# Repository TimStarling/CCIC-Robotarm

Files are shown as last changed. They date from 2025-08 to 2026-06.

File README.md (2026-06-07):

<div align="right">

[中文](README.md) | [English](README_EN.md)

</div>

# CCIC-Robotarm
基于海云捷讯的机械臂控制系统-2025年集成电路创新大赛（集创赛）FPGA应用赛道作品（机械臂控制部分）
本项目分为两个工程，视觉识别部分参见另一个仓库（视觉识别部分）
注意：ip核的版本可能和你的quartus不一致，将.qip文件中的版本号改成和你的quartus版本一致即可

基于 FPGA 的机械臂控制工程（2025 集成电路创新大赛 FPGA 应用赛道参赛项目，机械臂控制部分）。本仓库聚焦 **“坐标/仓库信息输入 → 逆解与动作编排 → 串口下发舵机/气泵指令”** 的完整链路。视觉识别侧在另一个仓库中维护。

---

## 1. 项目概述

本设计运行在 Intel Cyclone IV E（EP4CE6F17C8）平台，使用 Quartus Prime Lite 23.1 工程。顶层模块会在触发后完成一次自动搬运流程：

1. 根据目标点 `(x, y)` 计算机械臂姿态（高位/低位）。
2. 串口下发 5 路舵机位姿。
3. 控制气泵吸取/释放物块。
4. 根据仓库编号查询目标仓位坐标与方向。
5. 将物块放置到仓位后回到初始位。

顶层状态机实现了完整时序（等待、抬升、下降、吸放、回零）。

---

## 2. 代码与工程结构

```text
.
├── rtl/                    # Verilog RTL 源码
│   ├── data_send_top.v     # 顶层：流程控制状态机 + 各子模块联动
│   ├── xyz_calculate.v     # 坐标到舵机 PWM 的逆解计算
│   ├── all_instruction.v   # 5 路舵机角度顺序发送调度
│   ├── single_instruction.v# 单条舵机协议发送
│   ├── uart_Robot_tx.v     # 机械臂串口发送
│   ├── uart_tx_pump.v      # 气泵串口发送
│   ├── warehouse.v         # 仓库坐标/方向获取
│   ├── key_detect.v        # 按键消抖与沿检测
│   └── ...
├── quartus_prj/            # Quartus 工程（qpf/qsf/ip/output_files 等）
├── 技术文档.pdf             # 设计说明文档（中文）
└── 参数.txt                # 机械臂参数/调试记录
```

---

## 3. 顶层接口说明（`data_send_top`）

### 输入

- `sys_clk`：系统时钟（工程管脚绑定到 `PIN_E1`）。
- `sys_rst_n`：低有效复位（`PIN_E15`）。
- `key1`：启动按键输入（代码中取反后做按下检测）。
- `uart_rx`：仓库信息串口输入（`PIN_N14`）。
- `rx_camera`：视觉串口输入（`PIN_L13`，当前逻辑中仅透传到测试口）。

### 输出

- `tx_armcontrol`：机械臂舵机串口输出（`PIN_E7`）。
- `tx_pump`：气泵串口输出。
- `tx_done`：一次多舵机串口批量发送完成标志。
- `tx_test`：测试口（当前接 `rx_camera` 透传，`PIN_G1`）。
- `control_finish`：整套抓取放置流程完成标志。

---

## 4. 核心流程（状态机）

顶层 `state` 从 `d0` 到 `d24` 组织整个流程，关键阶段如下：

- **启动与参数锁存**：检测按键触发，锁存当前目标和偏移量。
- **物料区高位 → 低位**：先到高处，再下降抓取。
- **气泵吸取**：下发吸气指令并延时等待稳定。
- **查询仓位**：通过 `warehouse` 模块获取目标仓位坐标与方向。
- **仓位高位/低位放置**：到仓库高位、下降、放置、再抬升。
- **回初始位并结束**：回到默认姿态，置 `control_finish=1`。

> 说明：当前版本里视觉输入模块 `uart_camera` 实例被注释，`x_input/y_input` 在上电后有默认值（`132/80`），适合联调与离线动作验证。

---

## 5. 开发环境与构建

- Quartus Prime Lite: **23.1std.0**（工程创建版本）
- Device: **EP4CE6F17C8**
- Top-level entity: **`data_send_top`**

### 编译步骤

1. 打开 `quartus_prj/Robot_arm.qpf`。
2. 检查 IP 是否可用；若版本不一致，按本机 Quartus 版本重新生成或调整 `.qip` 关联。
3. 运行 `Analysis & Synthesis`、`Fitter`、`Assembler`。
4. 在 `quartus_prj/output_files/` 获取 `Robot_arm.sof` 并下载到 FPGA。

---

## 6. 串口与联调建议

- 机械臂舵机与气泵各自独立串口发送，请确认外设波特率与协议匹配。
- `all_instruction` 采用“单舵机逐条发送 + 延时”策略，便于避免总线拥塞。
- 若接入视觉仓库联动，建议先单独验证：
  1. `xyz_calculate` 输出范围；
  2. `warehouse` 返回坐标/方向的时序；
  3. 气泵指令在各状态的触发时机。

---

## 7. 已知注意事项

1. **IP 版本兼容性**：跨 Quartus 版本时，`.qip` / IP 可能需重新生成。
2. **工程输出目录较大**：`quartus_prj/db`、`output_files` 为编译产物。
3. **视觉模块默认未使能**：如需在线视觉坐标，请恢复 `uart_camera` 实例并检查协议。

---

## 8. 后续可优化方向

- 恢复并标准化视觉输入协议，形成完整闭环自动分拣。
- 将状态机中的固定延时改为可配置参数（或依据反馈闭环结束）。
- 增加仿真 testbench（坐标、仓位、串口返回场景）。
- 增加异常处理：串口超时、仓位无效、吸取失败重试。

---

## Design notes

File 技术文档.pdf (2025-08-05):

1

# 第九届

# 全国大学生集成电路创新创业大赛

报告类型： | 技术报告
参赛杯赛： | 海云捷讯杯

## 作品名称：基于海云捷讯 FPGA 的机械臂精确控制系统设计

队伍编号： | CICC0902660
团队名称： | I'm milk dragon

2

## 基于海云捷讯 FPGA 的机械臂精确控制系统设计 —

## — 快速预览简介

一、核心系统架构
本作品以海云捷讯 AWC_C4 DVK 开发板的 Cyclone IV 系列 FPGA （EP4CE6F17C8N）为核心，构建了集图像采集、处理、机械臂控制于一体的精 确控制系统。系统外接 OV5640 摄像头（720P 分辨率，RGB565 格式）实时采 集图像，经 FPGA 处理后通过 VGA 接口显示；SDRAM 模块（HY57V2562GTR， 256Mbit）用于图像缓存，采用乒乓操作实现跨时钟域（84MHz 摄像头输入 / 75MHz VGA 输出）数据同步；通过串口与 6 自由度飞特总线舵机通信，完成物 块抓取与放置。
二、关键技术亮点
1. 视觉处理优化方案
色块识别：采用 RGB 转 YCbCr 颜色空间转换（公式： Y=0.299R+0.587G+0.114B，Cb、Cr 同理），相比 HSV 减少 FPGA 逻辑资源 占用，实现 95%-100% 的颜色识别正确率（红色、蓝色 100%，黄色 98%， 黑色 95%）。
边缘检测：基于 Sobel 算子的 4 级流水处理，通过缓存 3 列像素计算水 平 / 垂直梯度，快速提取物块边框，为形状识别奠定基础。 角度计算：结合颜色角点（Z 字型扫描逐次逼近获取）与边缘角点（边框范 围内检测），利用 CORDIC 算法实现反正切计算，正方形、三角形角度误差 ±2°-6°，圆形、六边形通过对称性修正后精度提升。
2. 机械臂控制高效实现
逆运动学解算：采用基于余弦定理的方案，通过 Matlab 预计算所有可能坐 标对应的关节角度及 PWM 值，生成 ROM 表（如以 X、Y 为地址存储 PWM0 和 R 值），FPGA 查表调用，减少 90% 以上实时计算资源占用，角度误差 ±0.1°，末端定位误差 < 1mm。
PWM 控制：12 位精度（4096 级），舵机角度误差 ±1 步进，配合状态机 实现抓取 - 放置全流程自动化，单目标处理链路延迟 < 20ms。 三、核心性能指标
识别精度：颜色识别综合正确率 98%，形状识别中正方形 98%、三角形 93%、圆形 90%、六边形 89%；角度计算误差最大 6°（正方形 135° 时）。

3

控制精度：机械臂抓取成功率 86%-96%（中心区域最高 96%），逆运动学解 算末端误差 < 1mm，PWM 输出精度满足舵机 0.09°/step 控制需求。 实时性：图像处理支持 30fps 视频流，单帧处理时间 < 33ms；控制闭环 （图像采集到指令输出）延迟 < 20ms。
资源占用：采用 ROM 查表方案后，FPGA 逻辑资源占用 84%，记忆资源占用 75%。
系统已满足赛题难度 1、2 要求，当前物块放置精度 90%。

4

目录

5

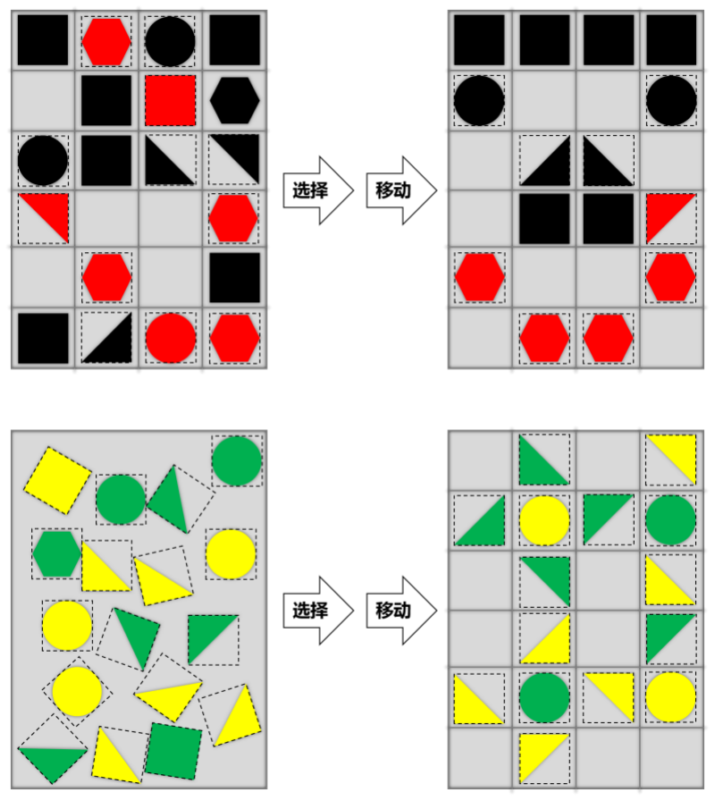
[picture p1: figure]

6

## 1 系统架构分析

1.1 赛题介绍

本赛题内容为控制多自由度机械臂完成将一定数量含有不同形状和颜色图 案的正方形物块，按照指定规则进行仓库至目的地的移动、拼接和还原。 示意图如图 1 所示：

图 1.1 设计要求示意图
本赛题要实现的内容：
1、传感器数据处理：FPGA 可以实时处理来自 OV5640 图像传感器的数据， 对图像数据实时进行 RGB 转 YCbCr、图像二值化、生长算法、目标检测、颜色 识别、计算坐标等算法实现。
2、运动控制算法实现：通过 FPGA 实现机械臂的运动控制算法，在 Matlab 中完成逆运动学计算、ROM 设计、轨迹规划控制。将这些算法可以通过硬件描 述语言实现，利用 FPGA 的并行计算能力对算法加速处理。 3、通信接口设计：本设计需要用到 IIC、UART、VGA 等接口，实现摄像头 参数配置、机械臂串口通信、调试串口通信、图像显示等功能。各接口通过 FPGA 并行处理能力实现同步运行，确保摄像头配置、机械臂控制、调试监控及 图像显示功能高效协同。
1.2 系统总体设计

本系统以 FPGA（EP4CE6F17C8）为核心控制器，构建起集图像处理、特征提 取、机械臂控制于一体的高精度运动控制系统，实现对目标物体的精准抓取与

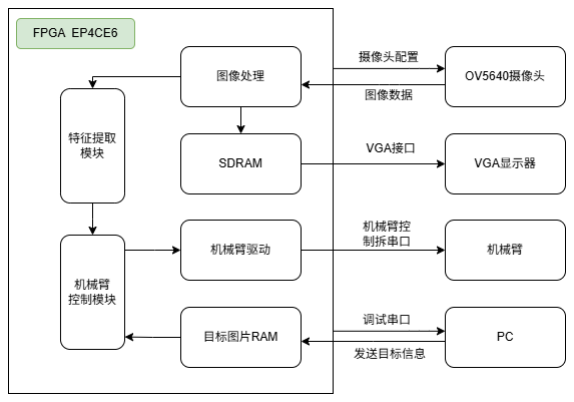
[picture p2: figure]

7

操作。系统外接 OV5640 摄像头实时采集场景图像，经 FPGA 内部图像处理模块 进行 RGB565 转 YCbCr、灰度二值化、腐蚀膨胀算法、目标检测生长算法和颜色 识别等处理，提升图像质量并提取目标特征、坐标等数据，处理后将图像数据 存入 SDRAM 缓存，同时通过 VGA 接口输出至显示器以便实时监控。特征提取模 块对处理后的图像进行分析，计算目标物体的坐标、形状、颜色等关键信息并 传递给机械臂控制模块，该模块结合逆运动学计算、轨迹规划等算法生成机械 臂各关节控制指令，通过机械臂控制串口发送至驱动模块，精准驱动机械臂执 行抓取动作。目标图片 RAM 用于存储目标物体特征信息以便快速调用匹配，PC 通过调试串口与 FPGA 通信，可发送目标信息或接收系统状态数据进行调试监 控。工作时，OV5640 先采集图像，经 FPGA 处理与特征提取识别目标，机械臂 控制模块中有预先在 Matlab 中计算好的逆运动学 ROM，驱动机械臂完成抓取， 同时 VGA 实时显示图像、PC 端辅助调试确保系统稳定。本组利用 FPGA 并行计 算特性实现图像处理与控制算法高效运行，缩短响应时间，提升实时性，模块 化设计增强可维护性与扩展性，各模块协同保障机械臂运动的高精度与稳定 性，通过整合多模块功能实现图像感知与机械臂控制的深度融合，为机械臂精 确控制提供高效可靠的解决方案。整个系统框图如下 图 1.2 所示：

图 1.2 系统总体框图
1.3 硬件设计

AWC_C4 DVK 是 Cyclone IV E 系列 EP4CE6F17C8N 的一款开发板，芯片 采用 28 纳米工艺。它集成了 6272 个逻辑单元、179 个 I/O 接口，封装为 FBGA - 256 形式，工作电压范围 1.15V~1.25V，工作温度范围 0℃~+85℃，总 RAM 位数达 276480bit。该芯片具备高性能，依托先进工艺与充足逻辑单元， 可实现高速运算与存储；支持用户根据需求编程，灵活实现不同场景下的功 能；开发板板载 SDRAM 为 256Mb，用于缓存图像数据、中间计算结果等，

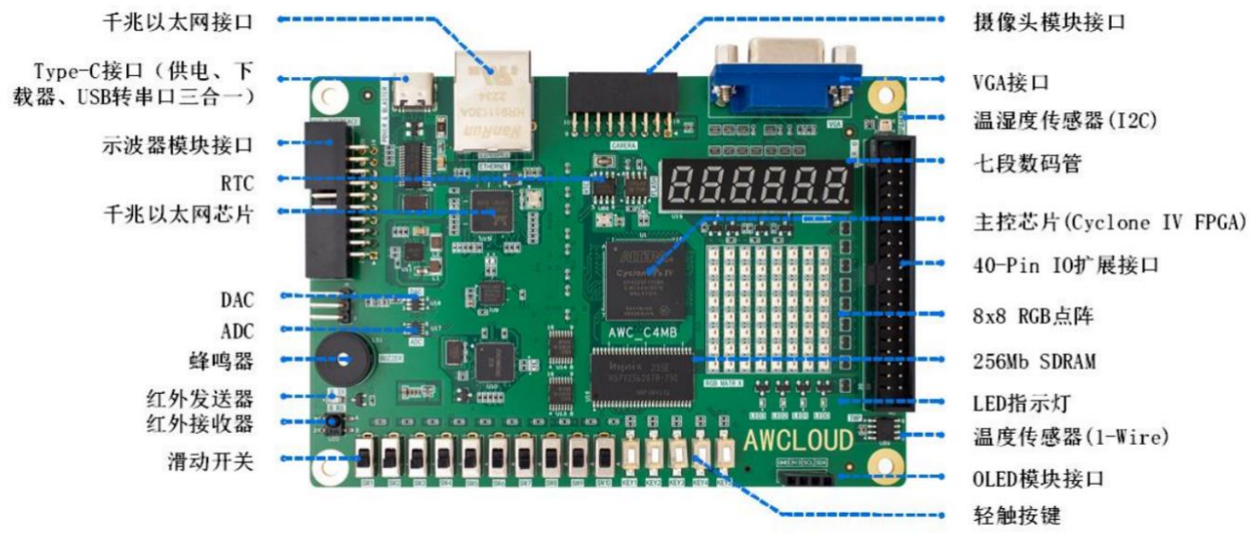
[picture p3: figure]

8

支持 FPGA 高速读写，保障系统数据处理流畅。 VGA 接口 传输模拟信号， 能连接显示器输出处理后的图像，便于调试与显示。 摄像头模块接口可接入摄 像头，为 FPGA 提供图像采集输入，适用于物体识别、图像处理等场景。 按 键为轻触式，用于触发功能或调整参数； 拨码开关则通过滑动设置状态组合， 直观输入配置信息。 拓展口可外接传感器、控制板等设备，灵活扩展系统功 能，增强开发板适用性。其他如电源、指示灯等部分为基础支持，确保各模块 稳定运行。下图为开发板示意图如 1.3 所示：

图 1.3 开发板示意图
1.3.1 SDRAM 模块
AWC_C4 DVK 上设计有 SDRAM 电路，主要用于协助主控芯片内部的命 令发送以及数据传输等。在图像处理系统中，需要对图像视频数据进行缓存， 所以需要大容量存储器。SDRAM 有价格优廉、容量大等优点，常作为 FPGA 的外挂存储器。同步是指其工作需要同步时钟，命令的发送与数据的传输都以 时钟为基准；动态是指存储阵列需要不断的刷新来保证电容存储体中的数据不 丢失；随机是指数据可以自由指定地址进行数据读写。该开发板采用的是 SK Hynix 公司 SDRAM，芯片型号为：HY57V2562GTR，容量为 256Mbit， （4Mx4Bankx16IO）同步动态随机存储器。使用的数据位宽为 16bit，最大工 作频率为 133MHz。
在项目中，OV5640 摄像头负责图像采集，利用 SDRAM 对处理后的图像 数据进行的乒乓操作，和跨时钟域处理。乒乓操作是一种高效的数据缓冲与处 理技术，利用存储模块交替进行数据写入和读出。在第一个缓冲周期，数据写 入模块 1；第二个周期，数据写入模块 2，同时读出模块 1 的数据，循环往 复。通过输入输出数据流选择单元的协同切换，使输入输出数据流连续不断， 可实现数据的无缝缓冲与处理。而跨时钟域操作，因 OV5640 输入的图像时钟 PCLK 为 84Mhz，VGA 的输出时钟为 75Mhz，直接操作易引发数据错误，利用 SDRAM 进行跨时钟域同步，有效解决因时钟域不同导致的数据一致性问题。

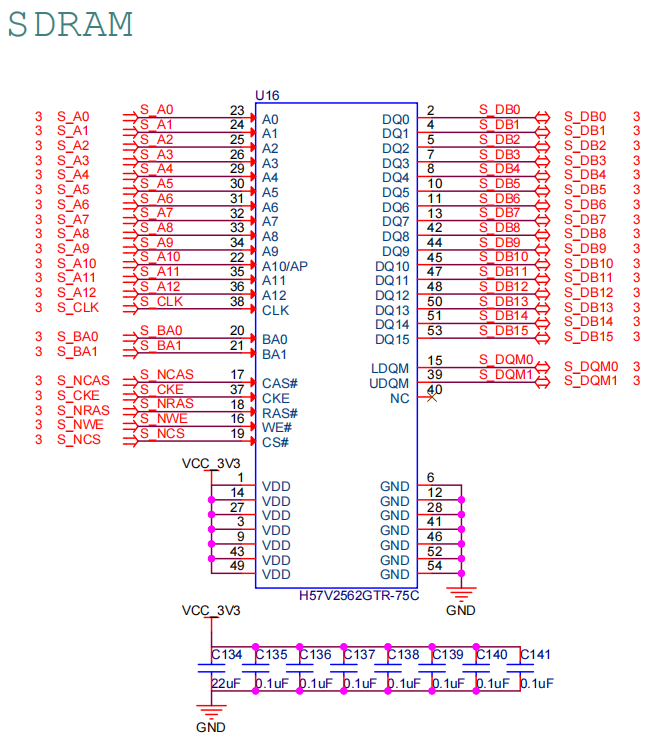
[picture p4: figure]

9

SDRAM 电路图如下图 1.4 所示：

图 1.4 SDRAM 电路图

SDRAM 模块引脚定义如 | 表 1.1 所示：
表 1.1 SDRAM 模块引脚定义表
信号名称 | 端口说明
S_DB0 ~ S_DB15 | SDRAM 数据线 0 ~ 15
S_DQM0 ~ S_DQM1 | SDRAM 数据掩码 0 ~ 1
S_A0 ~ S_A12 | SDRAM 地址线 0 ~ 12
S_BA0 ~ S_BA1 | SDRAM Bank 地址线 0 ~ 1
S_CLK | SDRAM 时钟输入
S_NCAS | SDRAM 列地址选通
S_CKE | SDRAM 时钟使能
S_NRAS | SDRAM 行地址选通
S_NWE | SDRAM 写使能
S_NCS | SDRAM 片选
1.3.2 摄像头模块
该项目用到摄像头模块，型号为 OV5640，实物图如图 1.5 所示：

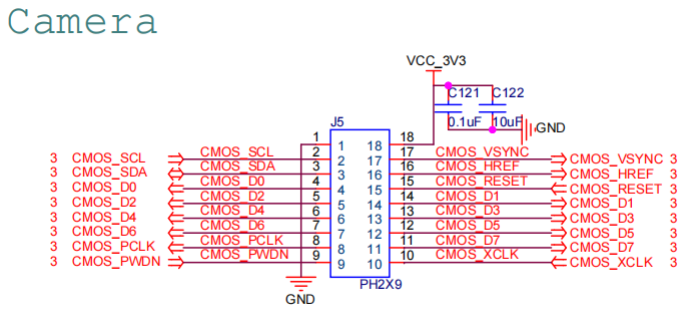
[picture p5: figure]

10

图 1.5 摄像头实物图
OV5640 是一款 CMOS 类型数字图像传感器，该传感器支持输出最大为 500 万像素的图像 (2592x1944 分辨率)，支持使用 VGA 时序输出图像数据， 输出图像的数据格式支持 YUV(422/420)、YCbCr422、RGB565 以及 JPEG 格 式。它还可以对采集得的图像进行补偿，支持伽玛曲线、白平衡、饱和度、色 度等基础处理。根据不同的分辨率配置，传感器输出图像数据的帧率从 15-60 帧可调。其内部有许多寄存器，用来配置摄像头的工作方式、图像格式等等； 在实际应用时需要先使用 SCCB 协议或者是 I2C 协议配置寄存器，使摄像头 按照常见的 VGA 时序输出图像数据。在本次设计中，使用 I2C 协议配置摄 像头，并将 OV5640 分辨率配置为 720P、数据格式为 RGB565 输出。 摄像头接口原理图如下图 1.6 所示：

图 1.6 摄像头接口原理图
摄像头接口模块引脚定义如 | 表 1.2 所示：
表 1.2 摄像头接口引脚定义表
信号名称 | 端口说明
CMOS_D0 ~ CMOS_D7 | 摄像头数据线 D0 ~ D7
CMOS_SCL | 摄像头 I2C 时钟线
CMOS_SDA | 摄像头 I2C 数据线

11

CMOS_PWDN | 摄像头掉电使能
CMOS_HREF | 摄像头行同步信号
CMOS_VSYNC | 摄像头帧同步信号
CMOS_RESET | 摄像头复位
CMOS_XCLK | 摄像头驱动时钟
CMOS_PCLK | 摄像头像素时钟
1.3.3 VGA 显示接口模块
VGA 是视频图像阵列，通常指代 VGA 接口。它是 IBM 在 1987 年推出 的一种视频传输标准，具有分辨率高、显示速率快、颜色丰富等优点，在彩色 显示器领域得到了广泛的应用。它的显示原理是： CRT（阴极射线管）以 “Z”型扫描的方式将阴极射线枪发出的电子束打在涂有荧光粉的荧光屏上， 产生 RGB 三基色合成一个彩色像素，每扫完一行，电子枪都要回到屏幕的下 一行左边的起始位置，并且在换行的过程中，电子枪需要消隐，避免破坏已经 成像的像素。
AWC_C4 DVK 上设计有 1 个 15 针的 D-SUB 接口，主要用于 VGA 输 出。开发板设计采用的是 R-2R 电阻梯形网络模拟 DAC（数模转换器）的简 易方案替换例如 ADV 系列的视频转换芯片，将数字信号转换为三种基色 （红、绿、蓝）模拟信号，以此降低成本。输出图像目前能支持 1024*768、
1280*1024 等分辨率。VGA 接口电路示意图如 | 图 所示：

图 1.7 VGA 接口电路图

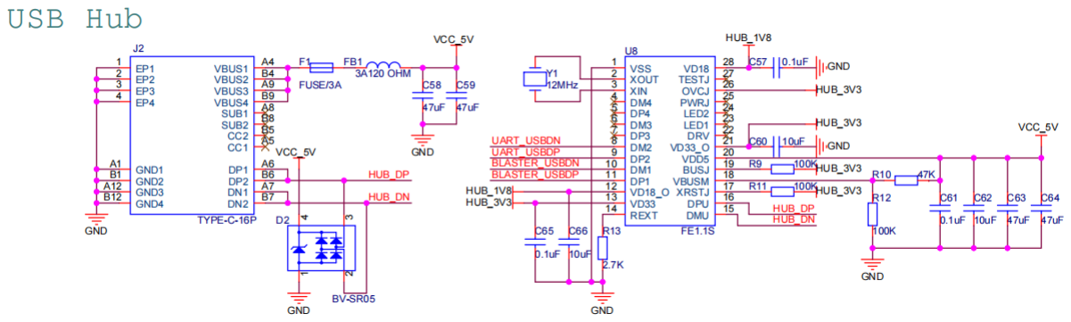
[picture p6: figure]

12

VGA 接口模块引脚定义如 | 表 1.3 所示：
表 1.3 VGA 接口模块引脚定义表
信号名称 | 端口说明
VGAD0 ~ VGAD4 | BLUE 数据输出 0 ~ 4
VGAD5 ~ VGAD10 | GREEN 数据输出 0 ~ 5
VGAD11 ~ VGAD15 | RED 数据输出 0 ~ 4
1.3.4 USB Hub 电路模块
AWC_C4 DVK 上设计有 1 个 USB Hub 电路，主要用于扩展 USB 接 口，以便于减少板上 USB 连接器数量从而优化板卡结构及空间。该部分电路 采用 TERMINUS 公司的 USB 芯片，型号为 FE1.1S，分出两路 USB 数据通 道。其中一路用于串口通信，另一路则为 USB Blaster II 下载器使用。USB Hub 电路如图 1.8 所示：

图 1.8 USB Hub 电路图

USB Hub 模块引脚定义如 | 表 1.4 所示：
表 1.4 USB Hub 模块引脚定义表
信号名称 | 端口说明
HUB_DP | USB 差分信号 P
HUB_DN | USB 差分信号 N
1.3.5 串口通信电路模块
AWC_C4 DVK 上设计有 1 个 USB 转 UART 电路，主要用于串口通 信。转换芯片采用的是 SILICON LABS 公司的 USB 芯片，型号为 CP2102-GMR，硬件电路如图 1.9 所示：

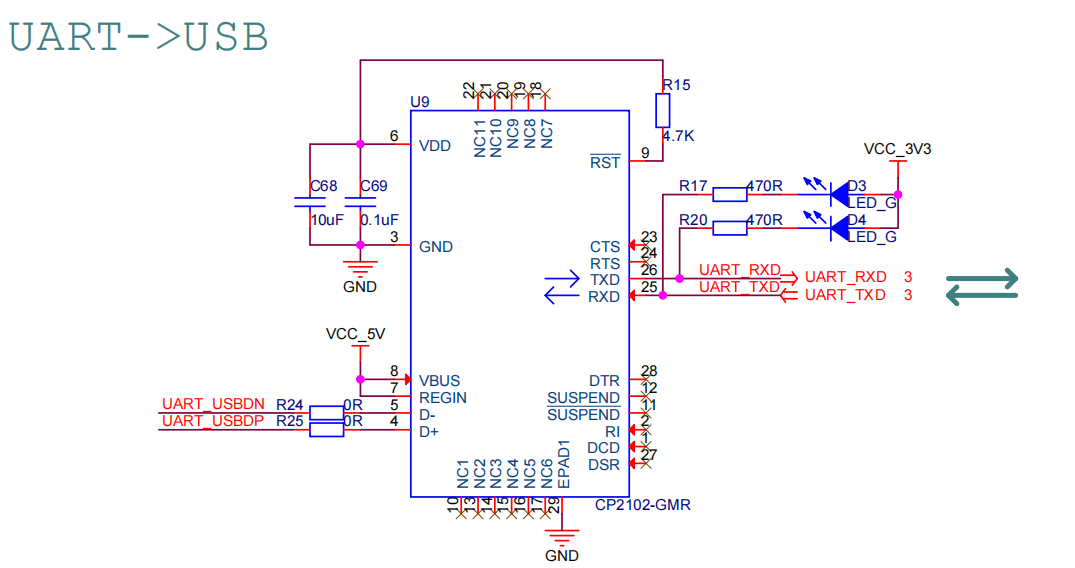
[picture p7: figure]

13

图 1.9 USB 硬件原理图
串口模块引脚定义如 | 表 1.5 所示：
表 1.5 串口模块引脚定义表
信号名称 | 端口说明
UART_TXD | UART 数据输出
UART_RXD | UART 数据输入

1.3.6 USB Blaster II 电路模块
AWC_C4 DVK 上设计有 1 个 USB Blaster II 电路，主要用于主控芯片程 序下载及调试。通常情况下，开发板上会设计有 1 个 JTAG 接口，可通过使 用 USB Blaster 下载器连接电脑 PC 和该接口，即可下载程序到主控芯片或者 固化程序到 Flash 后对系统进行调试与测试。但在本次设计中，不仅仅将 USB Blaster 下载器板载到开发板上节约成本，并且将其迭代至二代大大提升程 序下载速率。USB Blaster 二代下载器芯片采用的是小梅哥的 JTAG 芯片，型 号为 JTAG18M01HS2。此外，为匹配主控芯片上专用 JTAG 引脚电平要求 （2.5V），采用 TI 公司的 4 位双电源总线收发器芯片进行配置电压转换，型 号为 SN74AVC4T245PWR。USB Blaster II 电路如图 1.10 所示：

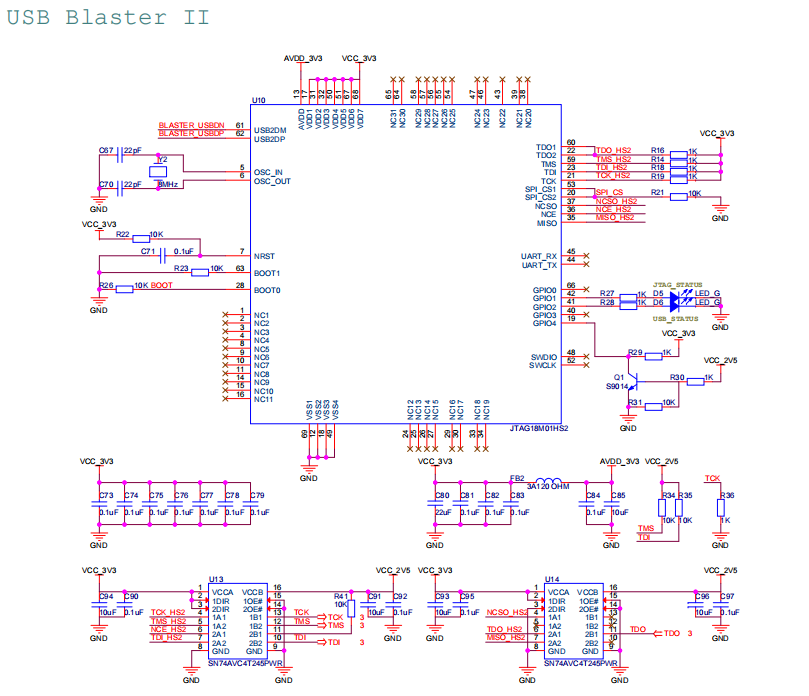
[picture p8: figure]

14

图 1.10 USB Blaster II 电路图

USB Blaster II 电路引脚定义如 | 表 1.6 所示：
表 1.6 USB Blaster II 电路引脚定义表
信号名称 | 端口说明
TCK | JTAG 时钟输入
TMS | JTAG 模式选择输入
TDI | JTAG 数据输入
TDO | JTAG 数据输出
1.3.7 机械臂模块
本项目使用到的机械臂为飞特的 6 自由度智能机械臂，实物图如图 1.11 所 示：

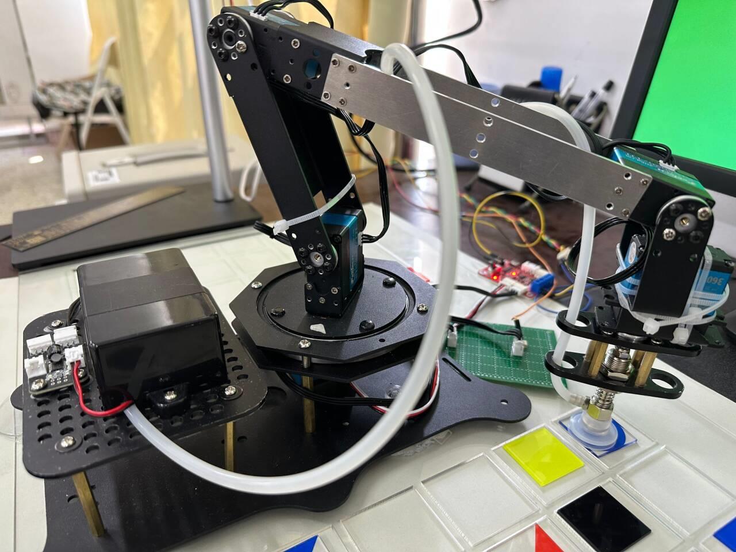
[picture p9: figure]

15

图 1.11 机械臂示意图
六自由度机械臂是一种具备六个独立运动自由度的机器人臂，通过六个关 节如基座旋转、下臂摆动、上臂伸缩弯曲、肘部扭转、手腕俯仰、手腕偏航 等，实现旋转或直线运动，使末端执行器能在三维空间中灵活调整位置与姿 态。其关节由电机驱动系统控制，通过改变各关节位置和角度达成所需动作。 该机械臂的舵机采用的是飞特的总线舵机。舵机如
图 1.12 所示：

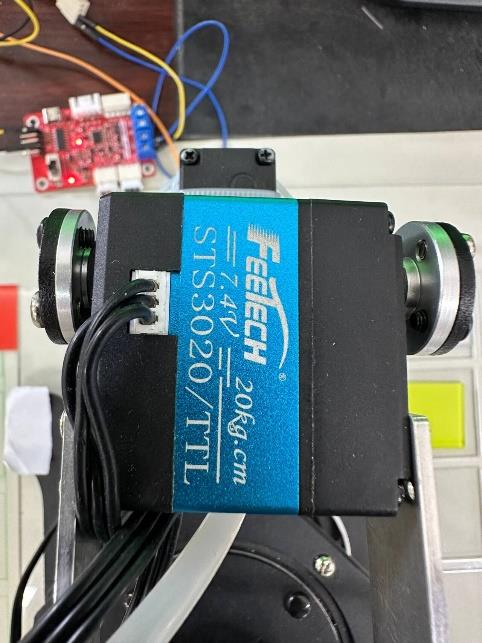
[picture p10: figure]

16

图 1.12 舵机实物图
下图是课题使用舵机驱动电路，该总线舵机可支持串口通信和 PWM 直驱。驱 动电路如图 1.13 所示：

图 1.13 舵机驱动电路图
总线舵机是一种集成了电机、减速齿轮组、控制电路和通信接口的智能执 行器。它的主要功能是接收来自控制器的指令，并通过精确控制电机的转动来 实现特定角度的输出。
它突破了传统舵机的局限，具备诸多优势：布线极简，支持串联，通过少 数几条线即可控制多个舵机，避免大量线缆缠绕；能实时反馈位置、温度、速 度、电压、电流等数据，便于主控监控与调整，预防堵转等故障；采用数字传 输信号，抗干扰强，通信灵活可靠且支持双向通信；每个舵机有唯一 ID，可通 过指令精准控制单个或多个舵机，还能实现开机回中位等功能。其应用广泛， 涵盖机器人、机械臂、智能车等领域，能简化系统设计，提升控制精度与灵活 性，即使非专业人员也能快速上手，缩短开发周期，为相关项目开发（如仿人

17

机器人、机械臂）提供高效便捷的解决方案，减少主控板端口占用，方便调试 与维护。

## 2 关键技术分析

2.1 视觉处理部分

2.1.1 色块识别
本赛题主要识别以下目标色块，共有两种图像识别算法。目标色块如图 2.1 所示：

图 2.1 目标颜色色块图
（1）图像处理算法总共有两种方案：
方案一：将 RGB 数据转化为 HSV 颜色空间，再分别对不同阈值进行二值 化，得到不同颜色的二值图像。公式如下：

H

{

0

∘
ifmax = min
60∘ ×

g−b
max−min

+ 0

∘
, ifmax = randg ≥ b

60∘ ×

g−b
max−min

+ 360∘
, ifmax = randg < b

60∘ ×

b−r
max−min

+ 120∘
, ifmax = g
60∘ ×

r−g
max−min

+ 240∘
, ifmax = b

式（2-1）

S{

0, | ifmax = 0
max−min
max

= 1 −

min
max
, otherwise | 式（2-2）
V = max | 式（2-3）
方案二：将 RGB 数据转化为 YCbCr 颜色空间，再分别对不同阈值进行二值 化，得到不同颜色的二值图像。公式如下：
{

Y = 0.299R + 0.587G + 0.114B
Cb = −0.1687R − 0.3313G + 0.5B + 128 Cr = 0.5R − 0.4187G − 0.0813B + 128

式（2-4）

根据上述两个方案，YCrCb 转换逻辑简单，调试与验证容易，开发周期 短。HSV 转换因复杂运算与条件判断，硬件描述语言实现时易出错，资源占用 率大，增加开发成本与风险。在 FPGA 资源有限的情况下，YCrCb 更易实现稳

18

定、可靠的设计，确保系统整体性能。所以在本次赛题中 YCbCr 计算复杂度、 实时性、兼容性及硬件实现难度上更适配，能高效满足机械臂精确控制系统对 图像快速处理与实时传输的需求，是更优选择。
（2）目标检测总共有两种方案：
方案:一：多目标检测方法，将图像中的多个目标同时检测，一共需要检测 15 个目标，对 15 个目标的特征信息如颜色、形状、坐标等实时检测。示意图 如下图 所示：

图 2.2 目标示意图
方案二：单目标检测方法，只检测单一目标，当机械臂将该目标搬走后， 再识别下一目标，得出相关特征信息。示意图如下图 2.所示：

图 2.3 相关特征示意图
根据上述两种方案对比仿真得出，在 FPGA 资源有限，方案二单目标检测仅 需一套检测电路，大幅减少逻辑资源占用，存储只需缓存当前目标数据，需求 低，且处理任务简单使功耗降低，代码量少、结构清晰，开发调试更便捷，资 源利用高效，更适合该题目。

### 2.1.2 Sobel 边缘检测

边缘检测模块基于 Verilog 实现，用于对转换来的 Y（亮度）分量进行边缘 检测。通过 Sobel 算子计算图像像素梯度，识别出图像中的边缘信息。得到 物块的边框

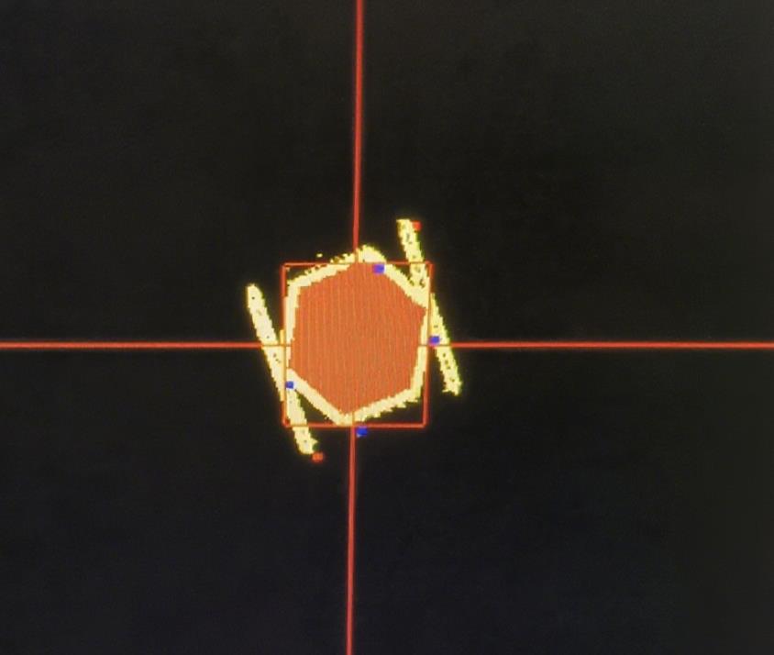
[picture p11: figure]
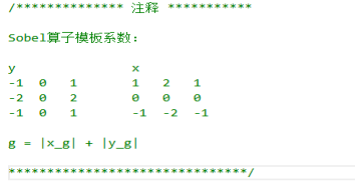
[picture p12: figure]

19

图 2.4 边缘检测边框
算法实现采用经典 Sobel 算子模板，分别定义 x（水平）、y（垂直）方向模 板系数：

图 2.5 模板系数

使用 quartusIP 核例化内存为 8 位 RAM 模块做窗口像素核 4 级流水计算 Y 分量 梯度，最后通过比较梯度大小与设定的阈值进行比较，获得边缘信息。

20

图 2.6 边缘信息获取代码

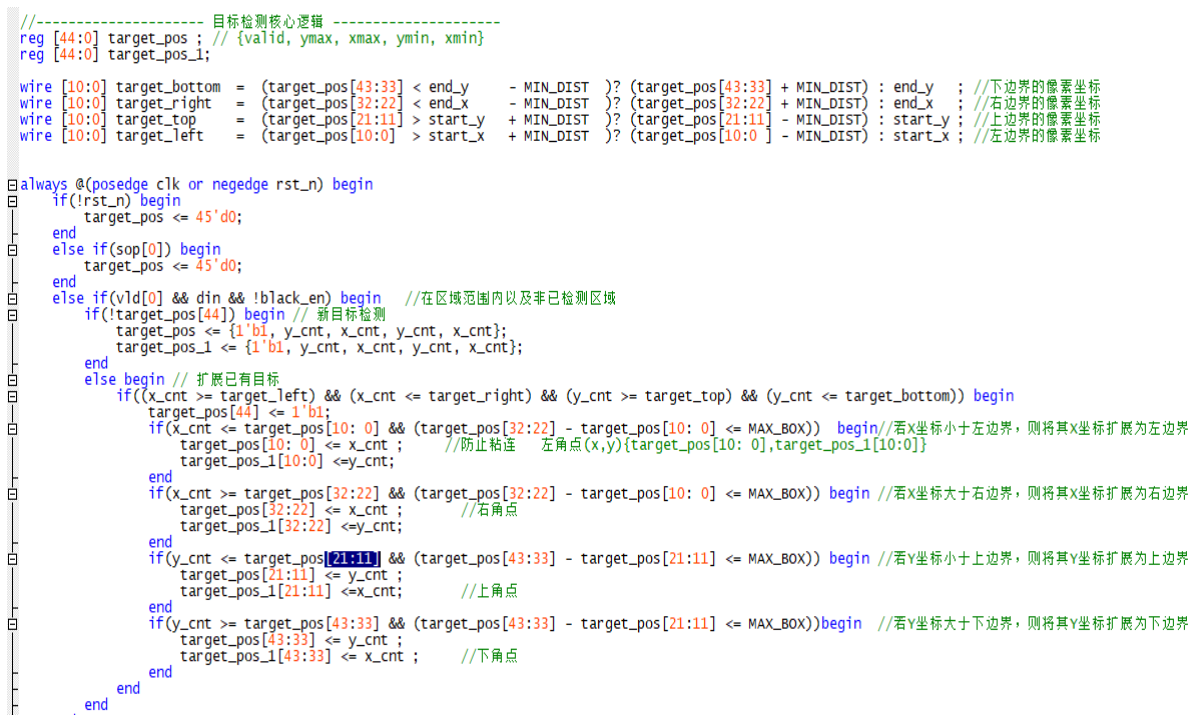
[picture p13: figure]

21

### 2.1.3 旋转角度识别

### 2.1.3.1 颜色角点

使用摄像头从左到右边，从上到下的 Z 字型扫描逻辑，当二值化获得物块 的颜色信息有效时，记录当前的 xy 坐标分量，逐步逼近的思想获得角点信息。 这里用获取上角点的坐标举例，当二值化信息有效，即当前点的颜色信息 为目标颜色时，第一次与设定的初值 VGA 屏幕上最下面的点做对比，若大于这 个值，则用 target_po[21:11]s 寄存器去寄存，当第二次扫描到的点二值化信 息有效时，若此时 y 坐标小于 target_pos[21:11]的值，即更新 target_po[21:11]，这样逐次逼近得目标物块的上角点。以下为具体代码:

图 2.7 角点信息获取代码

图 2.8 角点示意图

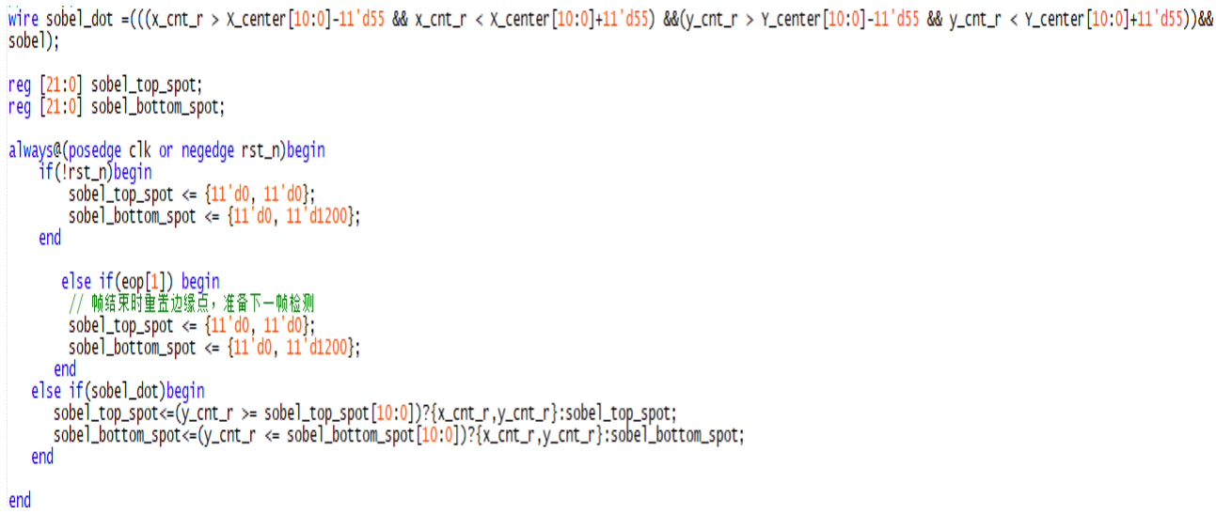
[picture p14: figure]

22

2.1.3.2 边缘角点
当检测到六边形和圆形时，由于两种图形具有对称性，因此无法仅从颜色 角点获得正确旋转角度。此时需要通过边缘识别获得边框的角点。 通过获取颜色角点的逻辑，在获得 4 个颜色角点坐标的基础上，可以获得 物块的中心坐标，该中心坐标同样也为正方形方片的中心坐标，可以中心坐标 为圆心设置半径画圆去框定边缘检测的范围·，在这个范围内去做边缘检测角 点判断，角点判定逻辑使用识别颜色角点逐次逼近的逻辑，只需要把有效点换 成边缘检测的有效点就可以了，代码如下 ：

图 2.9 边缘检测代码

图 2.10 边缘检测的角点
2.1.3.3 正方形

提取目标物的 Top_JiaoDian（上角点）和 bottom_JiaoDian（下角点） 坐标，通过这两个角点确定水平与垂直方向的长度差。

23

将角点的水平长度差 H_Length（Top_JiaoDian[21:11] -bottom_JiaoDian[21:11]）和垂直长度差 V_Length（Top_JiaoDian[10:0] -bottom_JiaoDian[10:0]），右移 1 位后作为 CORDIC 模块的输入 x、y，计 算原始角度。

图 2.11 边缘检测代码
2.1.3.4 三角形

先通过目标物的水平长度 x_length 和垂直长度 y_length，结合中心坐 标 X_center、Y_center 与角点（Top_JiaoDian、bottom_JiaoDian、 left_JiaoDian、Right_JiaoDian ）的位置关系，判定 直角点位置 （zj_dot_pos，分上、下、左、右 4 种情况 ）。 1.上直角点（zj_dot_pos==0）：角度加 90°

24

2．下直角点（zj_dot_pos==1）：直接使用 CORDIC 原始输出

3.左直角点（zj_dot_pos==2）：角度减 45° 后加 270°

4.右直角点（zj_dot_pos==3）：角度加 90°

### 2.1.3.5 六边形

提取边缘特征点 sobel_top_spot（上边缘点）和 sobel_bottom_spot （下边缘点），通过这两个点的坐标差确定水平与垂直长度。 将水平长度差 H_Length（sobel_top_spot[21:11] -sobel_bottom_spot[21:11]）和垂直长度差 V_Length （sobel_top_spot[10:0] - sobel_bottom_spot[10:0]），右移 1 位后作为 CORDIC 模块输入。

25

利用六边形几何对称性，最终角度需在 CORDIC 原始输出基础上 减去 45°，并将结果与 90° 做修正（Box_theta_out<='d90-age ）

2.1.3.6 圆形
提取边缘特征点 sobel_top_spot（上边缘点）和 sobel_bottom_spot （下边缘点），通过这两个点的坐标差确定水平与垂直长度 将水平长度差 H_Length（sobel_top_spot[21:11] -sobel_bottom_spot[21:11]）和垂直长度差 V_Length （sobel_top_spot[10:0] - sobel_bottom_spot[10:0]），右移 1 位后作为 CORDIC 模块输入。

最终角度需在 CORDIC 原始输出基础上 减去 45°，并将结果与 90° 做修正

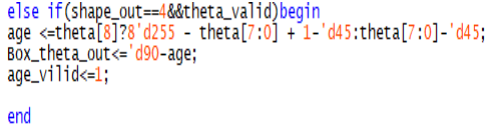
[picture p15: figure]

26

2.2 机械臂逆运动学计算部分

在本次项目中，由于 L3 是永远垂直水平面的，所以解算时可以相对取巧计 算，在逆运动学求解算法上有两种方案求取：
方案一如图 2.11 所示：

图 2.11 方案一示意图
该方案解算图如图所示，这种解算方法利用余弦定理，可以将各机械臂之 间的夹角计算出来，具体解算方法如下：
在得到目标坐标（x,y）后，通过式 2-5、式 2-6 可以得到

R = √x
2 + y
2 | 式（2-6）

L5 = √(L3 + Z − L0)
2 + R² | 式（2-7）

根据余弦定理公式 2-7 可得出θ2。

cos θ2 =

L1

2+L2

2−L5

2 2⋅L1⋅L2 | 式（2-8）

由公式 2-8 可得出θ4。

cos θ4 =

L1

2+L5

2−L2
2 2⋅L1⋅L5 | 式（2-9）

由公式 2-9 可得出θ5。

cos θ5 =

R L5 | 式（2-10）

综式 2-10、2-11 就可以计算出θ1、θ2、θ3 的值，最后换算为各机械臂舵机 PWM 值。
θ1 = θ4 + θ5 + 90∘ | 式（2-11）

27

θ3 = 360∘ − θ1 − θ2 | 式（2-12）
方案二如图 2.12 所示：

图 2.12 方案二示意图
该方案解算图如图所示，这种解算方法直接转化为简单数学表示，可以将 各机械臂之间的夹角计算出来，具体解算方法如下：
由于五边形内角和 540°，所以可得式 2-12。
θ1 + θ2 + θ3 = 90∘ | 式（2-13）
由简单数学变换得出式 2-13、2-14。
L1cos θ1 + L2cos θ3 = R | 式（2-14）
L0 + sin θ1L1 = L3 + z + sin θ3L2 | 式（2-15）
首先，将第三个方程改写为式 2-15。
L1sin θ1 − L2sin θ3 = L3 + z − L0 | 式（2-16）
令
C = L3 + z − L0 | 式（2-17）
则方程 2 和 3 可表示为式 2-17、2-19。
L1cos θ1 + L2cos θ3 = R | 式（2-18）
L1sin θ1 − L2sin θ3 = C | 式（2-19）
接下来，将这两个方程平方后相加，利用三角恒等式得到式 2-19。 (L1cos θ1 + L2cos θ3)

2 + (L1sin θ1 − L2sin θ3)

2 = R

2 + C

2 | 式（2-20）
展开并简化得到式 2-20。
L1

2 + L2

2 + 2L1L2cos (θ1 + θ3) = R 2 + C

2 | 式（2-21）
从而得到式 2-21。

cos (θ1 + θ3) =

R

2+C

2−L1

2−L2

2 2L1L2 | 式（2-22）

令
φ = θ1 + θ3 | 式（2-23）
则

φ = arccos (

R

2+C

2−L1

2−L2

2

2L1L2

) | 式（2-24）

接下来解方程组：

28

{

L1cos θ1 + L2cos θ3 = R
L1sin θ1 − L2sin θ3 = C

式（2-25）

将θ3表示为φ − θ1 ，代入方程式 2-24 并利用三角恒等式展开，得到关于θ1 的线性方程组式 2-25 和式 2-26。通过克莱姆法则求解，得到：

cos θ1 =

(L1+L2cos φ)R−L2sin φC
(L1+L2cos φ)

2+(L2sin φ)

2

式（2-26）

sin θ1 =

(L1+L2cos φ)C+L2sin φR
(L1+L2cos φ)

2+(L2sin φ)

2

式（2-27）

求出θ1 ，然后根据式 2-27 和 2-28
θ3 = φ − θ1 | 式（2-28）
θ2 = 90∘ − θ1 − θ3 | 式（2-29）
解出θ1、θ2、θ3 ，最后换算为各机械臂舵机 PWM 值。 但由于方案二计算难度较大，不易计算。且计算精度与方案一所差无几， 所以本项目选择方案一作为本次解算方案。
2.3 机械臂控制部分

选择完逆运动学解算方案后，我们需要考虑如何实现这一方案，由于考虑 到该计算存在大量浮点数、反三角函数、乘除法计算。
方案一：直接在 FPGA 中实时计算，会使用到 DIV、Mult、cordic 等大量 IP 核。
方案二：将这一部分逆运动学求解算法在 Matlab 中实现，根据已知（x，y）， 可以得出 R、θ0，并转化为 PWM，拼接后可以以 X、Y 为地址生成 ROM1（图 2.13）。当 R 唯一确定时，可以得出θ1、θ2、θ3 ，从而可以得出 PWM1、PWM2、 PWM3。以 R 为地址，PWM1、PWM2、PWM3 拼接在一起为数据，得到 ROM2（图 2.14）。

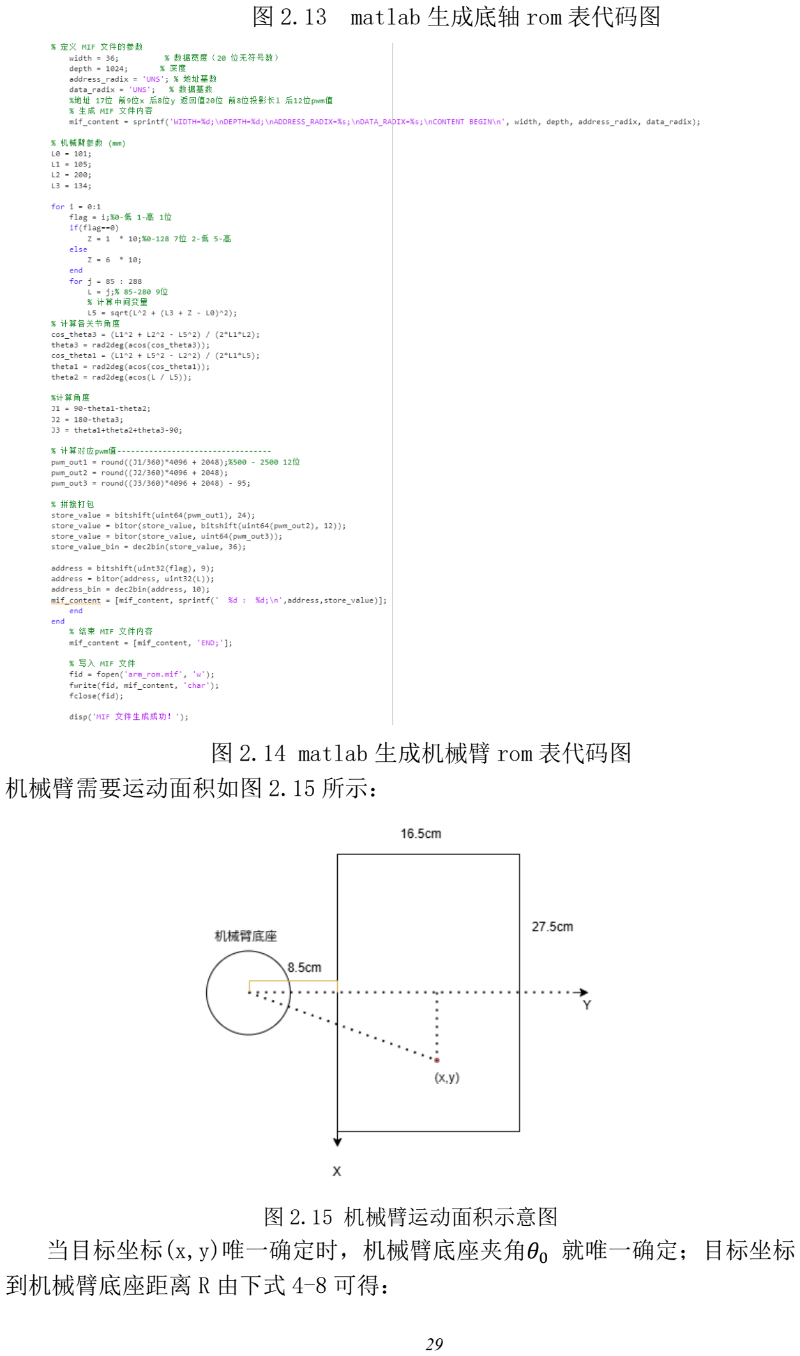
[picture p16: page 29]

29

图 2.13 matlab 生成底轴 rom 表代码图

图 2.14 matlab 生成机械臂 rom 表代码图 机械臂需要运动面积如图 2.15 所示：

图 2.15 机械臂运动面积示意图
当目标坐标(x,y)唯一确定时，机械臂底座夹角θ0 就唯一确定；目标坐标 到机械臂底座距离 R 由下式 4-8 可得：

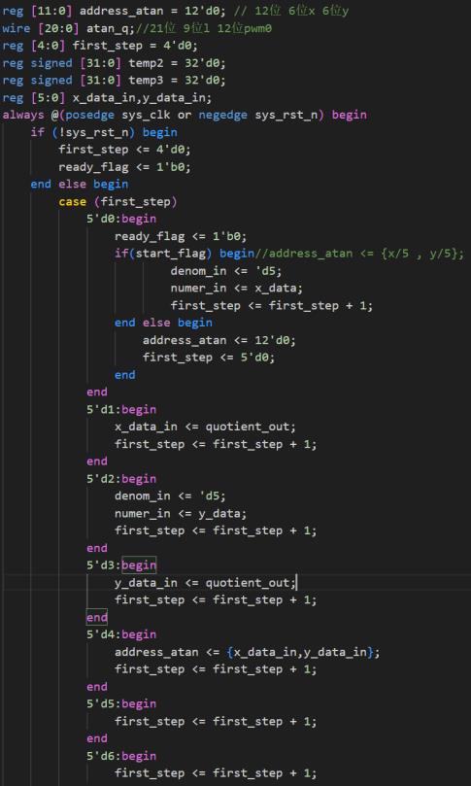
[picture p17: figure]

30

R = √x
2 + y
2 | 式（2-30）

所以可以用 Matlab 根据 x、y，计算出所有角度、PWM0、和 R 的值，以{X， Y}为地址，PWM0 和 R 为数据生成.mif 文件
综上两种方案，方案一资源占用过高，这些 IP 核尤其是乘法器（Mult） 和除法器（DIV）会消耗大量 FPGA 的 DSP 单元、逻辑单元（LE）等资源，可 能导致芯片资源紧张，限制其他功能模块的实现；其次，时序设计困难，复杂 IP 核如 CORDIC 运算延迟较大，多级 IP 核级联易引发时序违规，难以满足高 速时钟要求，影响系统实时性； 而方案二在 Matlab 中实现算法，生成 ROM 供 FPGA 查表，减少 FPGA 资源占用，时序设计简单，在 Matlab 中开发调试 高效，算法调整时仅需重新生成 ROM，维护成本低，且功耗更低，数据精度与 可靠性更高。所以在本项目中选择方案二作为机械臂控制方案。
2.4 动作组

整个动作组在收到视觉处理模块传回的坐标，角度，颜色，形状和使能信 号后开始执行，具体动作如下。
2.4.1 抓取
机械臂的控制为输入坐标（x，y）抓取和放置标志位以及使能信号，末端 即可到达坐标点。具体实现通过状态机依次进行位拼接读取 rom 中对应地址的 数据，以此返回机械臂各舵机的偏转角度，如图 2.16 所示。

图 2.16 rom 表读取代码图

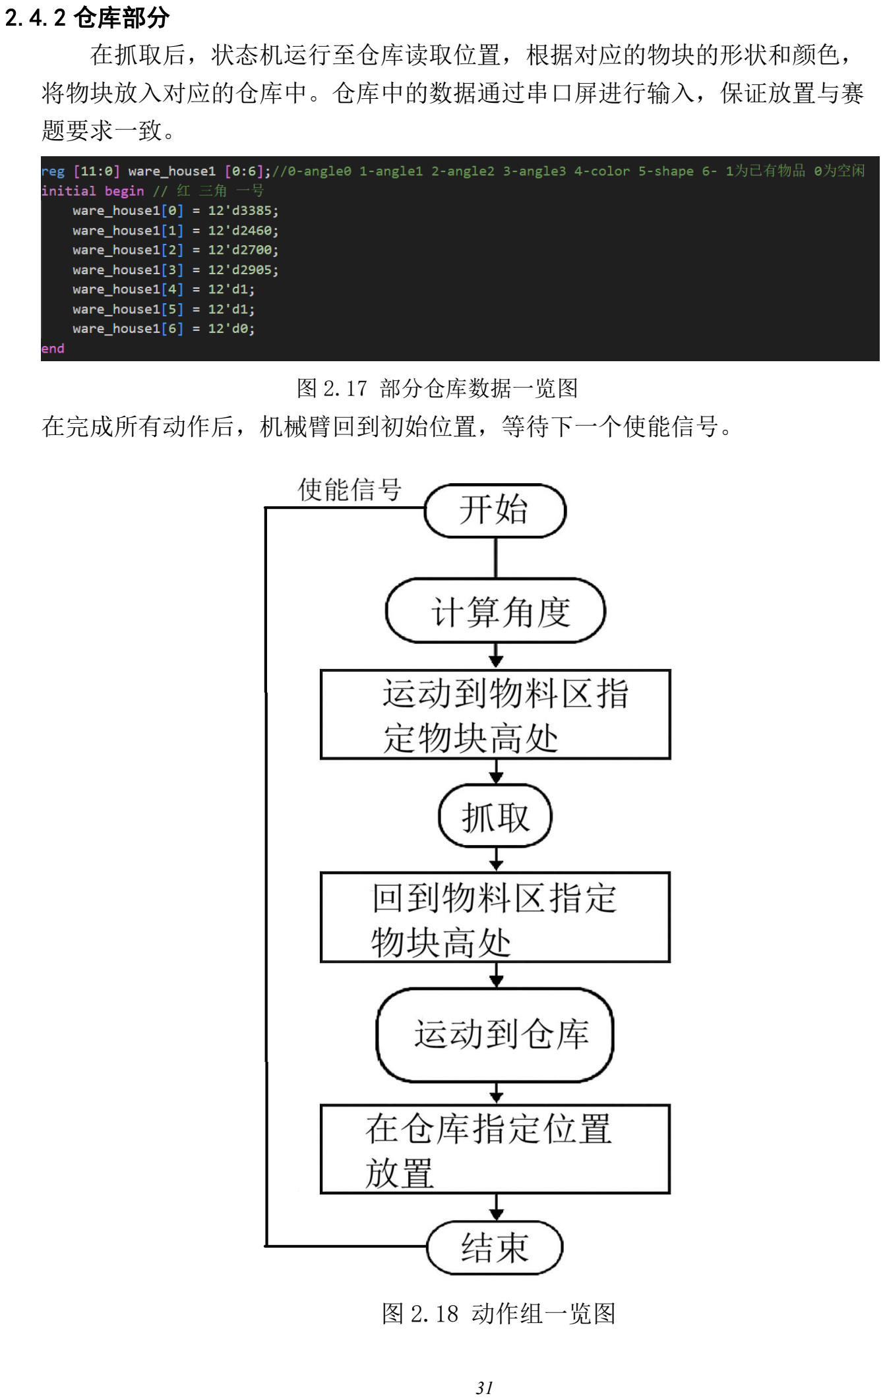
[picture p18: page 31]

31

2.4.2 仓库部分
在抓取后，状态机运行至仓库读取位置，根据对应的物块的形状和颜色， 将物块放入对应的仓库中。仓库中的数据通过串口屏进行输入，保证放置与赛 题要求一致。

图 2.17 部分仓库数据一览图
在完成所有动作后，机械臂回到初始位置，等待下一个使能信号。

图 2.18 动作组一览图

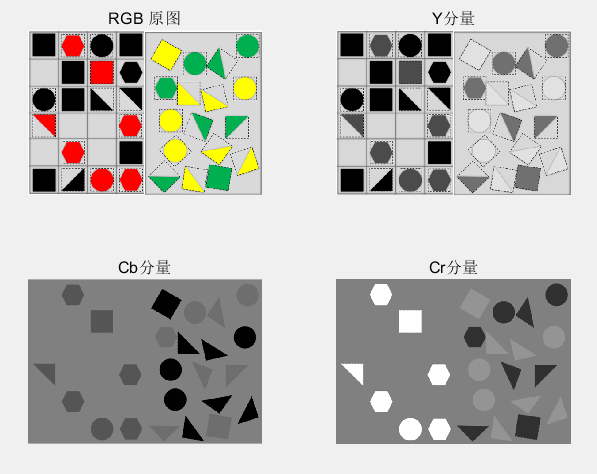
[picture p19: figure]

32

## 3 性能分析

3.1 图像处理算法仿真验证

3.1.1 RGB 转 YCbCr 算法仿真验证
使用仿真工具来进行测试，并观察仿真输出。确保仿真过程中没有出现错 误，并检查 YCbCr 分量的输出是否符合预期。经过 RGB 转 YcbCr 仿真结果如 图 3.3 所示：

图 3.3 仿真结果图
3.1.2 二值化算法仿真验证
YCBCR 颜色空间中，Y 代表亮度分量，Cb 和 Cr 代表色度分量 。将图像从 RGB 转换到 YCBCR 后，亮度和色度分离。在二值化时，对 Cb、Cr 色度分量设 置阈值进行操作，可减少光照变化对颜色判断的影响。因为光照变化主要影响 亮度（Y 分量），而对 Cb、Cr 影响小。也避免不同颜色之间的粘连问题，便于 后续处理，减少目标和复杂度如目标识别、形状分析、特征提取等处理会更简 便高效。本项目是根据不同颜色的阈值得出不同颜色的二值化图像再处理的。 二值化仿真图如下图 3.4 所示：

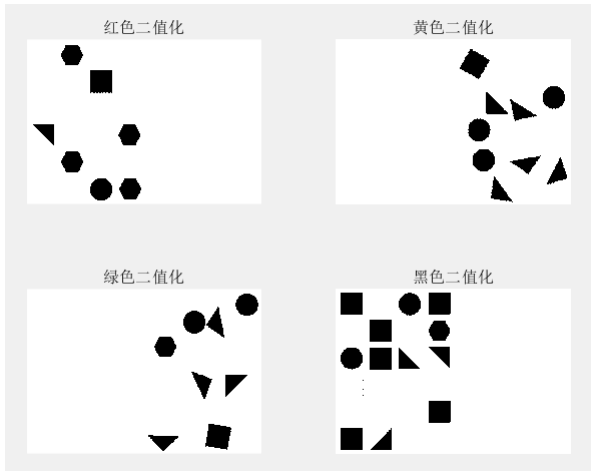
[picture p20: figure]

33

图 3.4 二值化仿真图

### 3.1.3 腐蚀膨胀算法仿真验证

腐蚀和膨胀算法在 FPGA 中的实现原理相差无异，均是采用移位寄存器生成 3*3 的模板，最后实现相与或者相或实现腐蚀膨胀算法。本项目采用先腐蚀后 膨胀的开操作图像处理方式，可以有效避除噪点且不失原有效图像数据。效果 如图 3.5 所示：

图 3.5 腐蚀膨胀仿真效果图

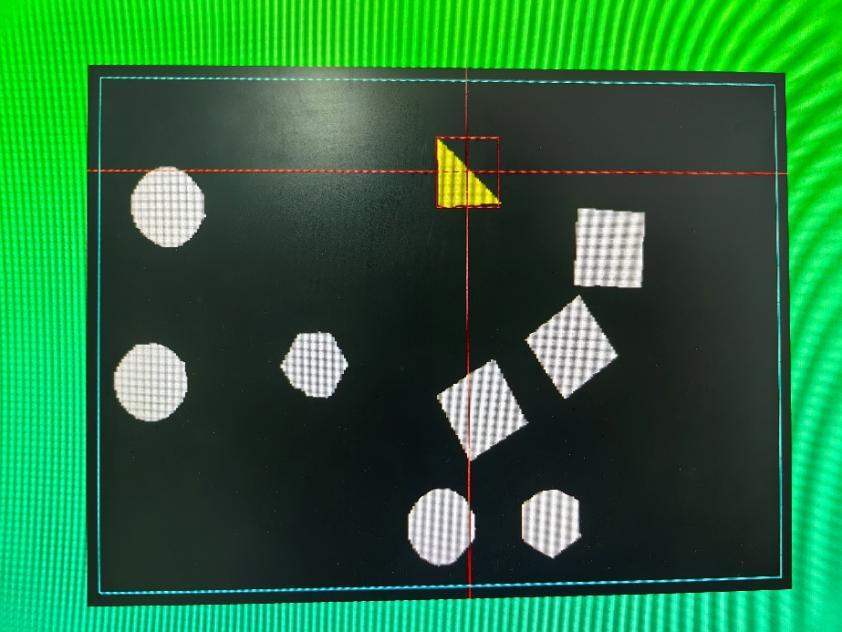
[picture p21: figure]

34

3.1.4 生长算法验证
区域生长算法是一种基于像素相似性的图像分割方法，其核心思想是从一 个或多个种子点出发，将与种子点具有相似属性的相邻像素逐步合并到同一区 域中，直至满足特定的停止条件。假设黄色三角形为种子点，算法会检测其邻 域像素，若邻域像素与种子点的属性差异在设定阈值内，便将该像素纳入生长 区域。如此循环，不断扩张区域。效果图如下图 3.6 所示：

图 3.6 生长算法效果图

### 3.1.5 CORDIC 算法

在 FPGA 中，传统的浮点三角函数计算复杂度较高，不利于硬件高效实现。因此，本

系统采用 CORDIC（COordinate Rotation DIgital Computer）算法，在仅使用加

减、移位与查表操作的基础上，实现反正切函数计算。CORDIC 算法基于坐标旋转思

想，通过一系列小角度迭代旋转逼近目标角度。对于初始点 | ，将其围绕原点旋
转角度 后得到新坐标 | ：

35

3.2 机械臂控制算法仿真验证

3.2.1 PWM 生成仿真验证
该模块是由特征提取模块得到的 x、y 值，再根据 Matlab 设计好的 ROM，提 取出各机械臂对应的 PWM 值，仿真图形如下图 3.7 所示：

图 3.7 PWM 仿真图
3.2.2 数字转字符串仿真验证
数字转 ASCILL 模块，是将对应的数字或特定字符转化为 ASCILL 形式，在 后续合成为控制指令发送给机械臂动作，仿真图如下图 3.8 所示：

图 3.8 数字转字符串仿真图
3.2.3 机械臂指令发送模块验证
在经过数字转 ASCILL 后，需要合成为一串特定指令，并通过串口发送到机

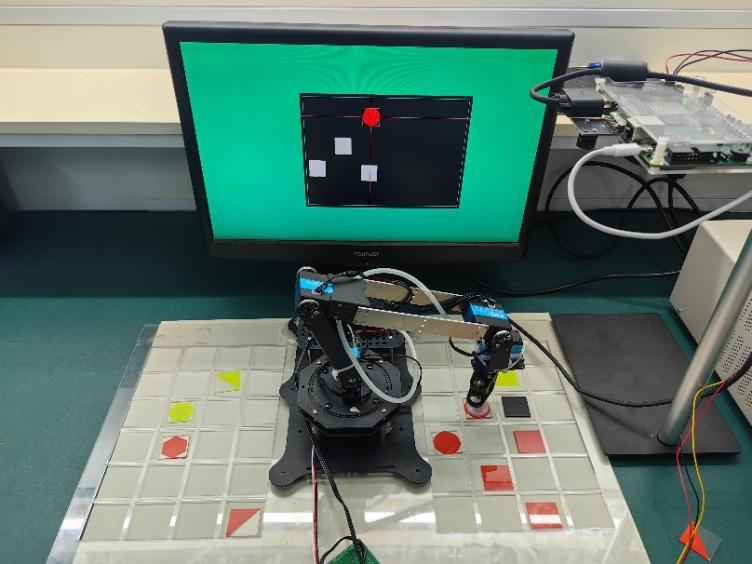
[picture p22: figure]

36

械臂做对应动作，该模块仿真图如下图 3.9 所示：

图 3.9 机械臂指令发送模块仿真图
3.2.4 上板测试
经上板进行实物测试，系统功能正常，图像识别精度高，机械臂分拣迅速 准确，验证了该系统的可行性。硬件搭建如图 3.10 所示：

图 3.10 实物演示图
3.3 控制精度分析

3.3.1 逆运动学解算精度
项目采用两种逆运动学求解方案，分别为：
方案一：基于余弦定理，通过公式逐步计算关节角度。
方案二：通过数学模型与三角恒等式推导角度，利用 Matlab 实现并查表获取。 最终选择方案二，核心优势在于数值稳定性高、查表方式减少了浮点误差的累 计。由于查表法可预生成高精度 ROM 表项，在 12 位舵机 PWM 精度下，角度误差 在±0.1°以内，转化到末端执行器的定位误差小于 1mm，远优于传统嵌入式计 算方式。
3.3.2 PWM 精度与舵机控制
舵机 PWM 由 FPGA 内部模块直接驱动，通过定时器与占空比调节实现脉宽输 出。PWM 分辨率为 12 位，即 4096 级控制，配合机械臂舵机本身的角度分辨率

37

（一般为 0.09°/step），最终实现了较高的动作精度。 实际测试表明，舵机角度输出误差控制在±1 步进以内，满足高精度搬运、定 位任务需求。
3.4 系统实时性分析

3.4.1 数据流与图像处理实时性
系统图像采集频率为 84MHz，VGA 输出频率为 75MHz，中间引入乒乓缓存机 制，确保图像读写操作并发进行，避免因带宽竞争引起的数据丢失或延迟。 由于图像处理任务如颜色识别、腐蚀膨胀等均在 FPGA 中并行实现，系统可在 1 帧图像周期内完成处理任务，确保在 30fps 视频流中做到每帧均参与计算，满 足大多数动态目标识别与控制需求。
3.4.2 控制链路响应速度
从图像采集到控制信号输出，整个控制闭环延迟在 20ms 以内。即：
- 图像采集处理：< 10ms
- 逆运动学解算：< 5ms（查表方式）
- PWM 指令生成与下发：< 5ms
此响应速度足以满足赛题要求的控制任务。
3.5 FPGA 资源利用率分析

方案一直接在 FPGA 中进行反三角、乘除法等复杂运算，会调用大量如 CORDIC、Mult、DIV 等 IP 核。这些核单元对 FPGA 资源消耗极大，尤其是 DSP 块与逻辑单元（LEs）：
CORDIC 模块：需多级流水线与 ROM 支持，占用大量寄存器与 LE；
DIV 除法器：需要大量时钟周期和控制逻辑。
而方案二则完全绕开了这些高消耗计算资源，采用 Matlab 离线计算 + ROM 查表方式，实际仅使用少量 BRAM 资源与查找逻辑单元。由查表 ROM 控制机械臂 的方法占 FPGA 资源的 16%左右，为视觉部分留足空间。如图 3.11 所示，最后 整体逻辑资源占用在 84%左右，记忆资源占用在 75%左右。

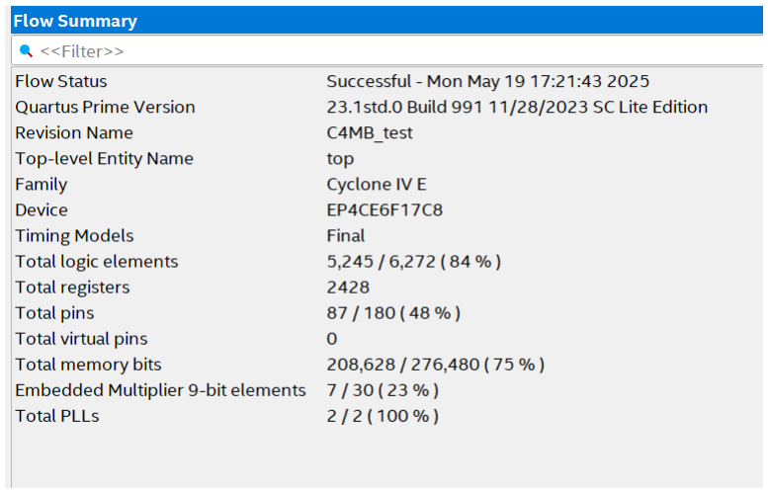
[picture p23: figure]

38

图 3.11 编译占用一览图

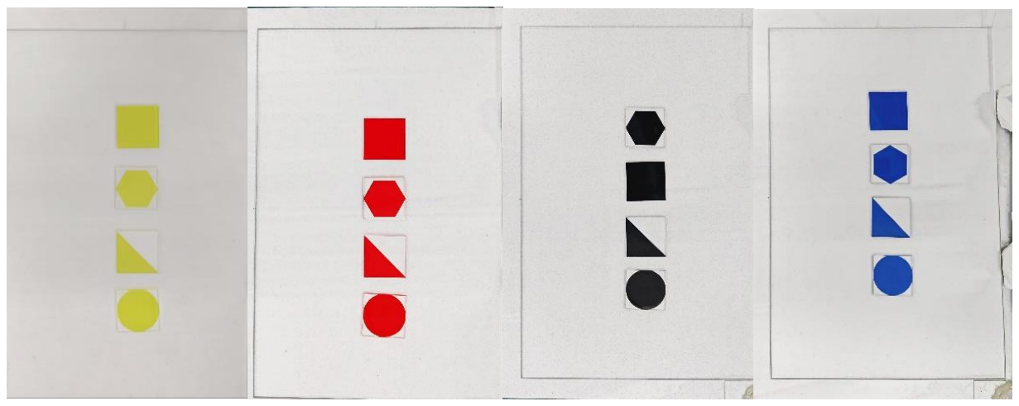
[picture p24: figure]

39

## 4 性能分析与测试

4.1 颜色识别准确度测试

本项目围绕基于 YCbCr 色彩空间的颜色识别技术展开，其算法流程为：摄像 头采集 RGB 图像信息，FPGA 使用流水线处理将 RGB 色域转化 YCbCr 色域，再通 过设定目标阈值实现对目标物体的识别。为验证该算法在实际使用环境下的稳 定性，本组在实际使用场景下开展了物体颜色识别，并统计得出不颜色识别的 准确率。

图 4.1 实际环境下的颜色识别实验

表 4.1 实际场景下颜色识别实验表

颜色 | 识别次数 | 颜色正确次数 | 正确率
黄色 | 100 | 98 | 98%
红色 | 100 | 100 | 100%
黑色 | 100 | 95 | 95%
蓝色 | 100 | 100 | 100%

40

通过上述实验数据可知，在实际场景下，物块颜色识别的综合正确率可达 98%，可以较好得达到系统的要求。然而，本实验只是对一般的场景进行的模拟 未对强光、弱光等非常规环境进行考虑，针对不同环境应根据实际的光照条件 确定颜色阈值以达到一个较好的识别效果。

4.2 图形形状识别

物块经过颜色识别之后，经过腐蚀膨胀算法去噪后，经过二值化处理后筛 选出需要识别的目标区域，系统再对筛选区域进行面积阈值的判断以区分不同 形状的物块。

六边形 | 正方形 | 圆形 | 三角形

图 4.2 形状检测实验结果

从实验的现象可以看出，经过对形状识别阈值阈值的初步优化对不同形状 的识别有了初步的效果，为了进一步测试系统的稳定性和优化形状识别阈值对 不同形状进行多次识别进行统计评估。

表 4.2 形状识别实验表

形状 | 识别次数 | 形状正确次数 | 正确率
六边形 | 100 | 89 | 89
正方形 | 100 | 98 | 98%
圆形 | 100 | 90 | 90
三角形 | 100 | 93 | 93

从实验的统计数据可以看出，整体的形状准确度在一个较好的水平，基本 可以达到系统的要求，但是对于圆形和六边形这类面积区分较小的图形识别准 确度会下降明显，后续考虑引入角点个数分析和细化面积阈值以进一步提高形

41

状识别的准确度。

4.3 机械臂运动精度

结合实际的应用场景和械机械臂机械精度的极限，综合考虑实现难度和效 果，我们将地图分割成 33×55 的等分，利用 MATLAB 软件计算出每个分割点对 应的机械臂姿态角度，存入 FPGA 的 ROM 存储器中，从而实现机械臂对地图物块 的抓取。

在实验中，首先通过视觉识别系统确定目标物体的位置坐标，并将这些坐 标传输给 FPGA 进行处理。FPGA 查找内部 ROM 读取对应坐标下的机械臂控制信 息从而控制机械臂实现抓取。

位置坐标 | 吸取次数 | 吸取成功次数 | 吸取成功率
(0,0) | 50 | 43 | 86%
(0,55) | 50 | 44 | 88%
(33,0) | 50 | 45 | 90%
(33,55) | 50 | 45 | 90%
(16,0) | 50 | 46 | 92%
(16,55) | 50 | 44 | 88%
(0,27) | 50 | 43 | 86%
(33,27) | 50 | 45 | 90%
(16,27) | 50 | 48 | 96%

实现取地图边缘点，中间点等特征点以估计机械臂的抓取准确度，根据表 中数据，机械臂抓取整体准确度在 87%以上，基本满足系统要求，在地图边缘 点的抓取上误差较大，中间点的抓取上误差较小，考虑对姿态计算公式做出改 进或引入视觉修正以求达到更加准确的抓取效果。

4.4 角度计算精度

物块的角度识别

FPGA 通过颜色角点计算物块与水平方向夹角，获取物块摆放的角度信息。 圆形和六边形对称性强，换为边框角度识别。

表 4.3 物块图案角度识别表（单位/°）

正方形 | 三角形
实际角
度

识别角
度

误差 实际角 度 识别角 度

误差

42

0 | 5 | 5 | 0 | 0 | 0
45 | 42 | 3 | 45 | 43 | 2
90 | 88 | 2 | 90 | 89 | 1
135 | 129 | 6 | 135 | 128 | 7
通过统计的信息可以看出正方与三角形的角度识别相对准确，在系统接收 的误差范围以内，也可以看出在角度偏移较大或较小时角度计算误差变大，考 虑优化角点识别算法，和角度计算算法以达到更高的角度计算精度。

4.5 透明外框角度识别

对圆形和六边形的处理利用边框的的角点算出物块与水平方向的夹角，与 色块角度测量配合计算出物块的旋转角度。

表 4.4 物块图案角度识别表（单位/°）

| | 正方形
| 实际角
度
| | | 识别角
度

误差

0 | 7 | 7
45 | 38 | 7
90 | 85 | 5
135 | 122 | 13

通过实验数据看出，边框角度的计算误差比色块的计算偏大，这与边沿检测算 法的敏感性和透明边框特征难以提取有关。考虑优化边缘检测算子以提高边框 角度识别精度。

43

5 结论

在本项目实施过程中，已成功达成赛题所设定的难度 1 与难度 2 要求。 现阶段，物块抓取精准性表现良好，但受限于机械误差因素，在将物块放置于 仓库时，其精准度尚存在一定提升空间，经统计，当前物块放置精准度约为 90%。在未来项目的持续开发与优化阶段，研究团队将着重针对机械误差展开精 细校准工作，并对现有算法进行深度优化，致力于实现物块放置精准度的进一 步显著提升，以期达到更为卓越的作业精准水平。

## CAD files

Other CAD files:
quartus_prj/db/stp1_auto_stripped.stp
quartus_prj/stp1.stp
quartus_prj/db/stp2_auto_stripped.stp

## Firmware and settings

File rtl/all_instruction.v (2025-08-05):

module all_instruction (
    input 					sys_clk		 ,
	input 					sys_rst_n	 ,

    //location1~5
    input    [15:0]     location1,
    input    [15:0]     location2,
    input    [15:0]     location3,
    input    [15:0]     location4,
    input    [15:0]     location5,

    
    //function
    input               Uart_en,

    output              tx,
    output       reg    Send_finish
);

// register 寄存器
reg                Uart_en_1;
reg                Uart_en_2;
reg                Delay_en_r;

//Delay
reg      [15:0]    div_cnt;  //分频系数 50_000-1 为1ms
reg      [13:0]    Delay_ms; //计数器  最大可计16384ms
reg                Delay_en;


//Seed
wire               finish;

reg      [3:0]     step;
reg                Send_en;
reg      [7:0]     ID;
reg      [15:0]    location;

//register
always@(posedge sys_clk or negedge sys_rst_n)begin
    if(!sys_rst_n)begin
        Uart_en_1<=0;
        Uart_en_2<=0;
        Delay_en_r<=0;
    end
    else begin
        Uart_en_1<=Uart_en;
        Uart_en_2<=Uart_en_1;
        Delay_en_r<=Delay_en;
        end
end

//分频
always@(posedge sys_clk or negedge sys_rst_n)begin
    if(!sys_rst_n)begin
        div_cnt<=0;   
    end
    else if(div_cnt==4_999)begin
        div_cnt<=0;
    end
    else if(Delay_en)begin
        div_cnt<=div_cnt+1;
    end
    else if ({Delay_en_r,Delay_en}==2'b10)begin
        div_cnt<=0;
    end
    else
        div_cnt<=div_cnt;

end

//计数
always@(posedge sys_clk or negedge sys_rst_n)begin
    if(!sys_rst_n)begin
        Delay_ms<=0;
    end
    else if (div_cnt==4_999)begin
        Delay_ms<=Delay_ms+1;
    end
    else if ({Delay_en_r,Delay_en}==2'b10)begin
        Delay_ms<=0;
    end          
    else
        Delay_ms<=Delay_ms;

end

//Seed
always@(posedge sys_clk or negedge sys_rst_n)begin
    if(!sys_rst_n)begin
        step<=0;
        ID<=0;
        location<=0;
        Send_en<=0;
        Delay_en<=0;
    end

    else begin
        case(step)

            0:begin
                 Send_finish<=0;

                 if({Uart_en_2,Uart_en_1}==2'b10)begin
                    step<=step+1;
                 end
            end

            1:begin
                            ID<=8'H05;
                          location<=location5;
                           Send_en<=1;
                           step<=step+1;
                    end

            2:begin
                            Send_en<=0;
                if(finish)begin
                    Delay_en<=1;
                    ID<=8'H04;
                    location<=location4;
                      end

                if(Delay_ms>500)begin
                    Send_en<=1;
                    Delay_en<=0;
                    step<=step+1; 
                end
                      
                else
                    step<=step;                                             
                    end
                    
            3:begin
                    step<=step+1;  //打一拍，避免Delay_ms没被清除就进入状态机的>500条件                   
                    end
                    
            4:begin
                            Send_en<=0;
                if(finish)begin
                    Delay_en<=1;						  
                    ID<=8'H03;
                    location<=location3;
                      end	

                if(Delay_ms>500)begin
                        Send_en<=1;
                       Delay_en<=0;
                       step<=step+1; 
                    end
                    else
                        step<=step;                                               
                    end
                    
            5:begin
                    step<=step+1;  //打一拍，避免Delay_ms没被清除就进入状态机的>500条件                   
                    end

            6:begin
                            Send_en<=0;
                if(finish)begin
                            Delay_en<=1;
                    ID<=8'H02;
                    location<=location2;
                        end
                    
                 if(Delay_ms>500)begin
                        Send_en<=1;
                       Delay_en<=0;
                       step<=step+1; 
                    end
                    else
                        step<=step;                                               
            end
                 
            7:begin
                    step<=step+1;  //打一拍，避免Delay_ms没被清除就进入状态机的>500条件                   
                    end


            8:begin
                Send_en<=0;
                if(finish)begin
                    Delay_en<=1;
                    ID<=8'H01;
                    location<=location1;
                                         
                end
                if(Delay_ms>500)begin
                        Send_en<=1;
                       Delay_en<=0;
                       step<=step+1; 
                    end
                    else
                        step<=step;                                               
            end						  

            9:begin
                Send_en<=0;
                if(finish)begin

                    Send_finish<=1;                       
                    step<=0;                                             
                end
            end
        endcase 
    end

end


single_instruction single_instruction_inst(
    .sys_clk(sys_clk),
    .sys_rst_n(sys_rst_n),
    .n2c_en(Send_en),
    .ID(ID),
    .location(location),
    .finish(finish),
    .tx(tx)
);

    
endmodule

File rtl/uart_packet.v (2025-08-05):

`timescale 1ns / 1ps
module uart_packet(
	input 				sys_clk,
	input 				sys_rst_n,
	input 		wire		uart_rx,
	
	
	output  reg [3:0] led,
	output  reg [4:0] location,
	output  reg [3:0] Shape,
	output  reg [3:0] color,
	output  reg [3:0] angle,
	output  reg       valid
	
);
	reg  [1:0]   		Rx_Done_r;
	wire [7:0] data_packet;
	wire           Rx_Done;
	
			  
	reg  [2:0] state;
	wire	posedge_Done;

always@(posedge sys_clk or negedge sys_rst_n)begin
	if(!sys_rst_n)
		Rx_Done_r<=0;
	else begin
		Rx_Done_r[0]<=Rx_Done;
		Rx_Done_r[1]<=Rx_Done_r[0];
		  end

end

assign posedge_Done=(Rx_Done_r==2'b01)?1:0;	
	

always@(posedge sys_clk or negedge sys_rst_n)begin
	if(!sys_rst_n)begin
		state<=0;
		location<=0;
		Shape<=0;
		color<=0;
		angle<=0;
		valid<=0;

	end
	else begin
	case(state)
		0 : begin		
					valid<=0;
					if(posedge_Done&&data_packet==8'hFF)begin//帧头
							state<=1;
					end
					 else begin
							state<=0;
							end
					 end
		1: begin
					if(posedge_Done)begin//仓库编号信息
							location<=data_packet[4:0];
							state<=2;
					end
					 else begin
							state<=1;								
							end
					end
		2: begin
					if(posedge_Done)begin//形状信息
							Shape<=data_packet[3:0];
							state<=3;
					end
					 else begin
							state<=2;								
							end
					end
		3: begin
					if(posedge_Done)begin//颜色信息
							color<=data_packet[3:0];
							state<=4;
					end
					 else begin
							state<=3;								
							end
					end
		4: begin
					 if(posedge_Done)begin//角度信息
							angle<=data_packet[3:0];
							valid<=1;
							state<=5;
					end
					 else begin
							state<=4;								
							end
					end
		5: begin
		         if(posedge_Done)begin//帧尾
						if(data_packet==8'hFF)begin
							valid<=1;
							state<=0;
							end
						else begin
							state<=0;									
							end
					end
					 else begin
							state<=5;								
							end
					 end
		default : state<=0;
		endcase
		end
	end

	always@(posedge sys_clk or negedge sys_rst_n)begin
		if(!sys_rst_n)
			led<=4'b1111;
		else begin
				if(location==1)begin
					led[0]=0;
				end
				if(Shape==1)begin
					led[1]=0;
				end
				if(color==1)begin
					led[2]=0;
				end
				if(angle==1)begin
					led[3]=0;
				end			
	end
end		
		
 UART_RX u_UART_RX(
/*input*/ 				.sys_clk(sys_clk),
/*input*/ 				.sys_rst_n(sys_rst_n),
/*input*/ 				.rx(uart_rx),
/*output reg[7:0]*/	.po_data(data_packet),
/*output reg*/ 		.po_flag(Rx_Done)  
);

endmodule
